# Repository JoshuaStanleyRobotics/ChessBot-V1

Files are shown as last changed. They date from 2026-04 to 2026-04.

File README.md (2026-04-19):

# ChessBot V1
ChessBot V1

This repository includes the PCB (gerber), CAD (.step), code (.ino and .py), and printing (.stl) files for ChessBot V1, an Arduino powered self-playing chess robot. 

A video overview of ChessBot V1 can be found here: [https://youtu.be/M-bemH251Hs](https://youtu.be/tLgXvUgsYmw)

The design has been updated slightly since the video, and the board coloring has been corrected to make A1 a black tile. The code is functional, but there is plenty of room for improvement. Feel free to modify the design and make it your own. Happy building! 

## Bill of Materials
| Component | Specs | Qty | Link |
|:---:|:-----:|:---:|:-----|
| ESP32 Dev Board | 38-pin version | 1 | https://www.amazon.com/dp/B0CNYK7WT2?ref_=ppx_hzsearch_conn_dt_b_fed_asin_title_14
| Electromagnet | 5V, 50N, 25mm diameter, 20mm height | 1 | |
| Motor Driver | DRV8872 | 1 |  |
| Hall Sensor | AH49FNTR-G1 | 64 |  |
| Momentary Switch | 6mm x 6mm | 2 |  |
| Barrel Jack Extension | 5.5x2.1mm | 1 | https://www.amazon.com/dp/B0D9B7WR23?ref_=ppx_hzsearch_conn_dt_b_fed_asin_title_1&th=1 |
| Power Supply | 7.5V, 36W, 5.5x2.1mm Barrel Jack | 1 | https://www.amazon.com/dp/B07N18XN84?ref_=ppx_hzsearch_conn_dt_b_fed_asin_title_3 |
| Stepper Driver | TMC2208 (or similar) | 2 |  |
| Stepper Motor | Nema 17, 22.5mm body height | 2 |  |
| Linear Rod | 8mm x 250mm | 2 |  |
| Linear Rod | 8mm x 265mm | 2 |  |
| Sleeve Bearing | 8mm ID, 10mm OD, 15mm length | 2 | https://www.amazon.com/dp/B07SLYD55F?ref_=ppx_hzsearch_conn_dt_b_fed_asin_title_4&th=1 |
| Sleeve Bearing | 8mm ID, 10mm OD, 6mm length | 6 | https://www.amazon.com/dp/B07SN3RBKW?ref_=ppx_hzsearch_conn_dt_b_fed_asin_title_1&th=1 |
| Timing Belt | 2GT 6mm | 5 meters |  |
| Belt Pulley | 2GT, 20 Teeth, 5mm ID | 2 |  |
| Idler Pulley | 3mm ID, 9.7mm OD, 13mm flange diameter, 8.5mm height | 12 |  |
| Neodymium Magnets | 8mm x 2mm | 32 |  |
| Button Head Screw | M3 x 30mm | 10 |  |
| Button Head Screw | M3 x 22mm | 2 |  |
| Button Head Screw | M3 x 12mm | 6 |  |
| Button Head Screw | M3 x 6mm | 8 |  |
| Washer | M3, 0.5mm thick | 50 |  |
| Threaded Insert | M3, 4mm thick | 24 |  |
| Rubber Feet | 3mm ID, 12mm OD, 6mm height | 4 |  |

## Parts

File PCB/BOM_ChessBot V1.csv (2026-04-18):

ID | Name | Designator | Footprint | Quantity | Manufacturer Part | Manufacturer | Supplier | Supplier Part | Price
1 | 10k | R1 | 1/4W RESISTOR | 1
2 | AH49F | A1,A2,A3,A4,A5,A6,A7,A8,B1,B2,B3,B4,B5,B6,B7,B8,C1,C2,C3,C4,C5,C6,C7,C8,D1,D2,D3,D4,D5,D6,D7,D8,E1,E2,E3,E4,E5,E6,E7,E8,F1,F2,F3,F4,F5,F6,F7,F8,G1,G2,G3,G4,G5,G6,G7,G8,H1,H2,H3,H4,H5,H6,H7,H8 | SC-59-3_L2.9-W1.6-P0.95-LS2.9-BR | 64 | AH49FNTR-G1 | DIODES(美台) | LCSC | C176936 | 0.535
3 | Stepper_Driver | U3,U4 | STEPPER_DRIVER | 2
4 | 100uF | C9,C10 | 8X12 CAP | 2
5 | ESP-WROOM-32 | U1 | ESP32 | 1
6 | XHB-2A | 5V,VCC | CONN-TH_XHB-2A | 2 | XHB-2A | BOOMELE(博穆精密) | LCSC | C57981 | 0.013
7 | HDR-M-2.54_1x6 | CN1 | HDR-M-2.54_1X6 | 1 |  |  | LCSC | C190819 | 0.041
8 | DRV8872DDARQ1 | U5 | SO-8_L4.9-W3.9-P1.27-LS6.0-BL-EP5.1 | 1 | DRV8872DDARQ1 | TI(德州仪器) | LCSC | C524788 | 1.79
9 | HDR-M-2.54_1x4 | M1,M2 | HDR-M-2.54_1X4 | 2 |  |  | LCSC | C124378 | 0.055

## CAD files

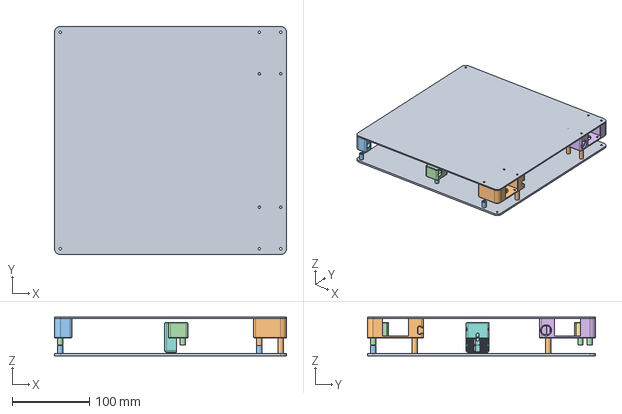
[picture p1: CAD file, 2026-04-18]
CAD/ChessBot V1.step
300.0 x 295.0 x 50.0 mm

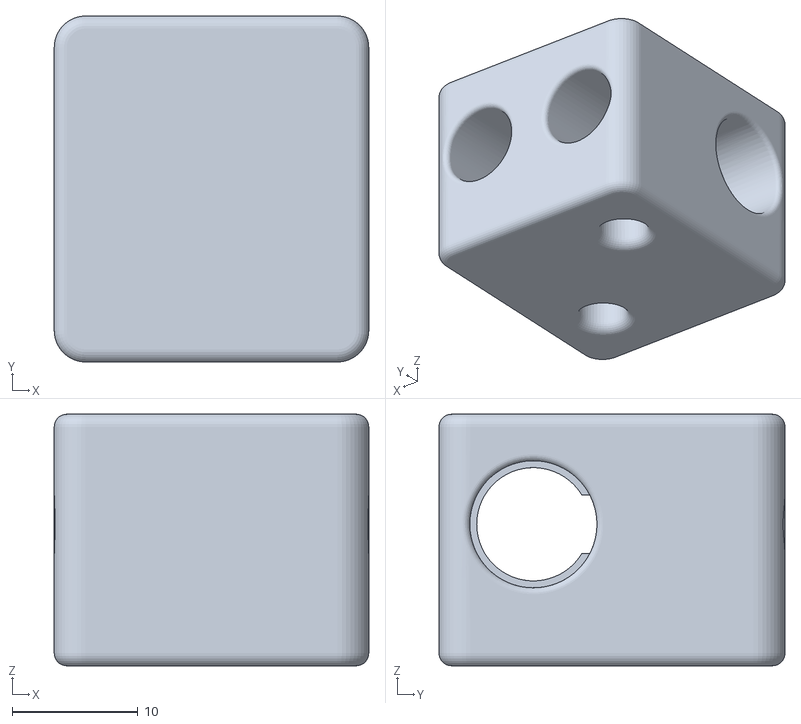
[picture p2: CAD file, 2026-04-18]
STLs/Gantry Carriage (A) - Qty 1.stl
25.0 x 27.5 x 20.0

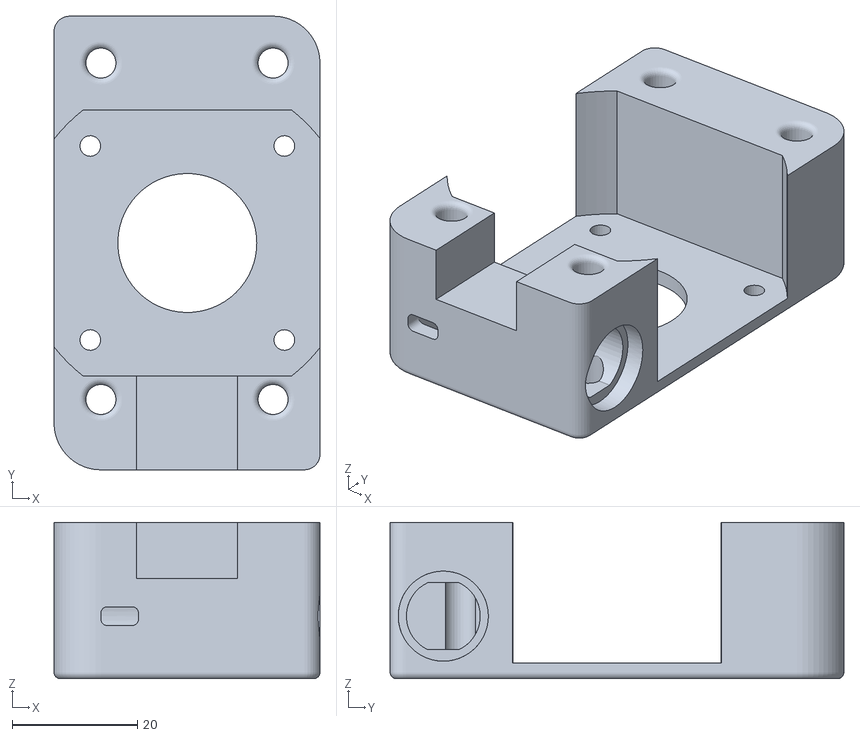
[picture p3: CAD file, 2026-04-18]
STLs/Motor Housing (B) - Qty 1.stl
42.5 x 72.5 x 25.0

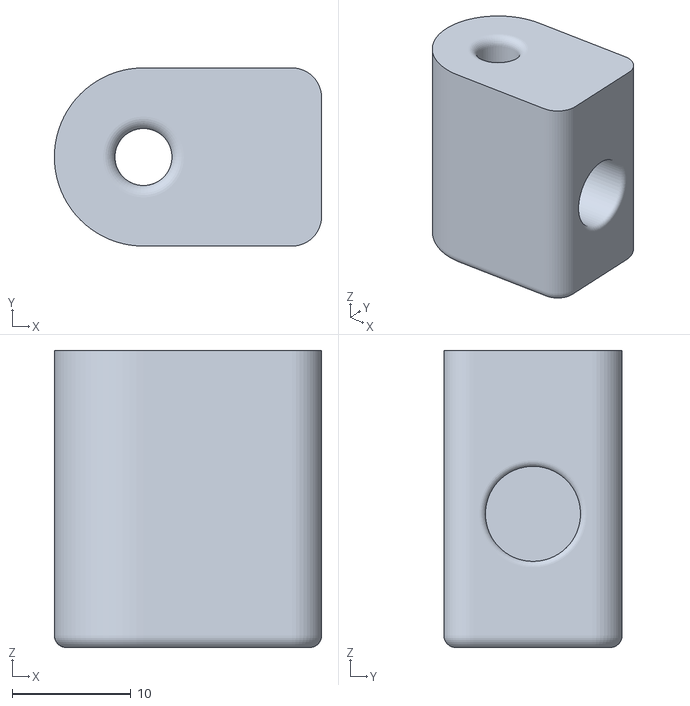
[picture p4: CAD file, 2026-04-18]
STLs/Corner Support - Qty 2.stl
22.5 x 15.0 x 25.0

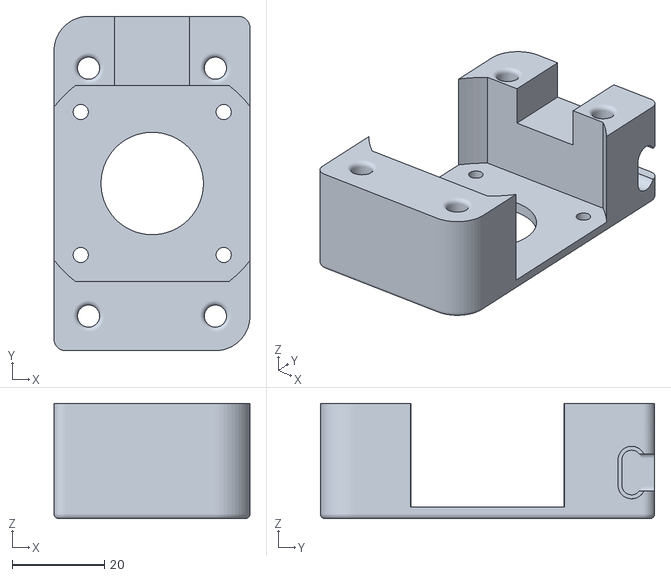
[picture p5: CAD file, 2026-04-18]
STLs/Motor Housing (A) - Qty 1.stl
42.5 x 72.5 x 25.0

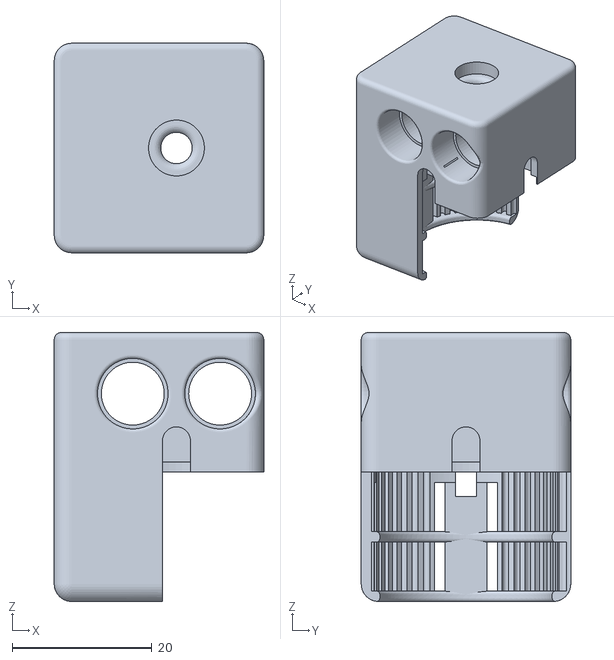
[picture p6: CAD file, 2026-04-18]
STLs/Magnet Carriage- Qty 1.stl
30.0 x 30.0 x 38.5

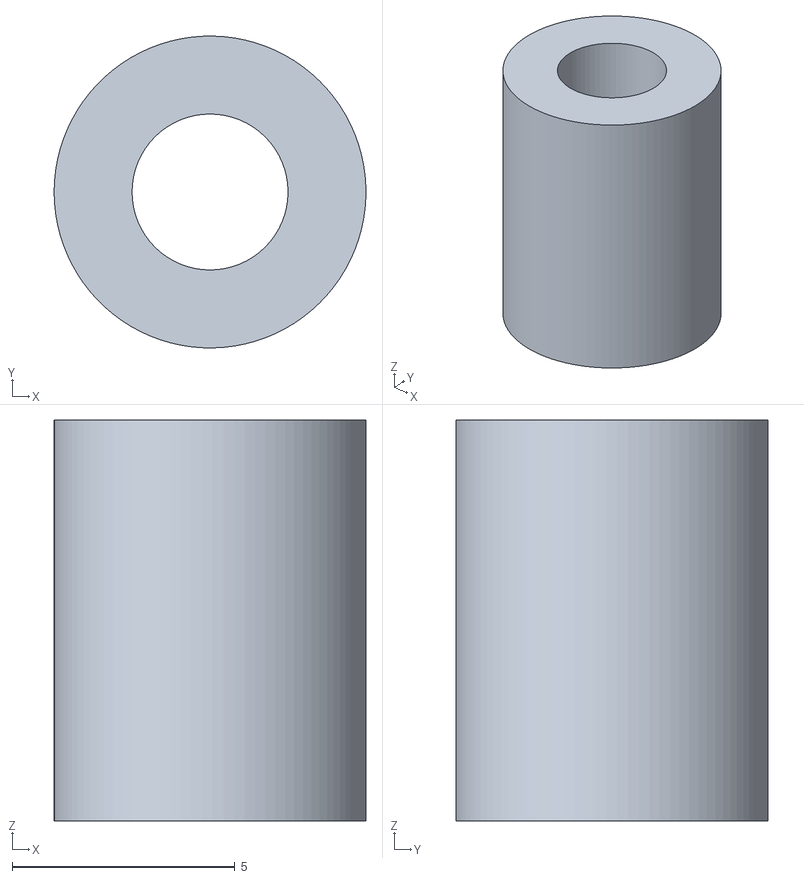
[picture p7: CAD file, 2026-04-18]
STLs/Spacer (short) - Qty 6.stl
7.00 x 7.00 x 9.00

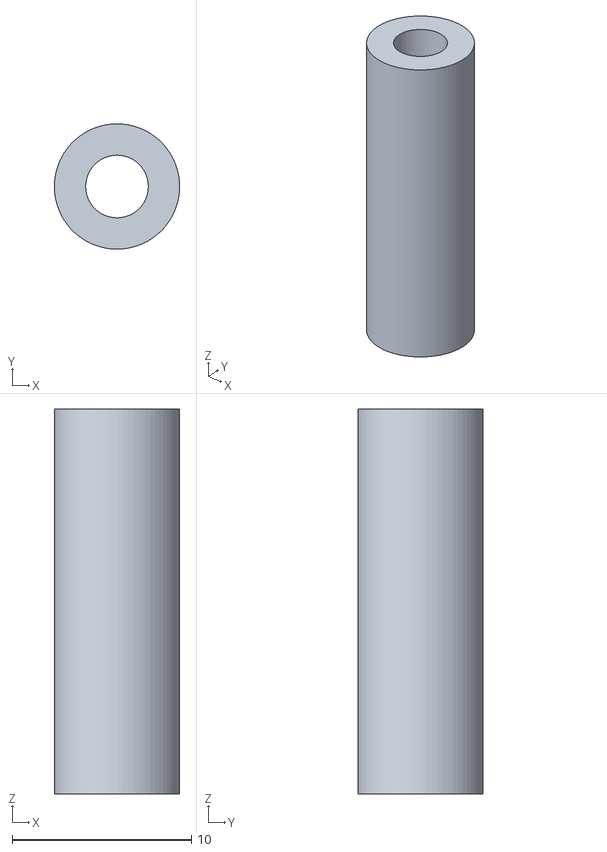
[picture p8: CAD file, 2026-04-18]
STLs/Spacer (long) - Qty 4.stl
7.00 x 7.00 x 21.5

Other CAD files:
STLs/Gantry Carriage (B) - Qty 1.stl

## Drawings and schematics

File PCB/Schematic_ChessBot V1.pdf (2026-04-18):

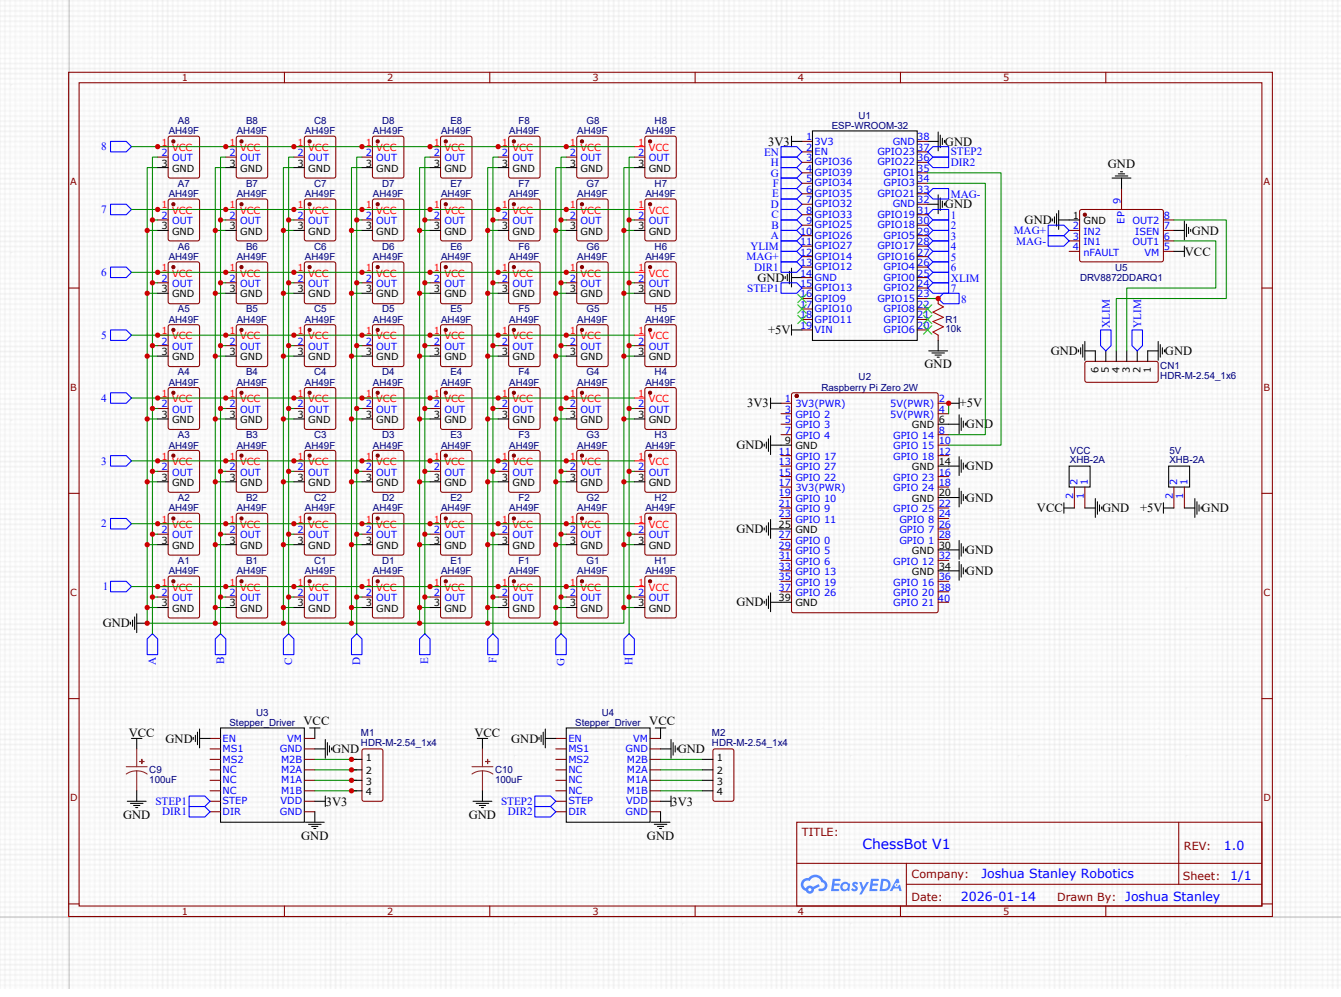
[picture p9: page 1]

Company: Joshua Stanley Robotics

Drawn By: Joshua Stanley

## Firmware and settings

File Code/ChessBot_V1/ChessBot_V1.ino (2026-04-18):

/*
   Description: This program is used to control a chess robot that reads the board state using hall effect sensors and moves pieces with an electromagnet on a coreXY motion system.
        The player's moves are communicated over serial to a computer running Stockfish which takes in the user's moves and responds with the computer's moves.
*/

//Libraries
#include "AccelStepper.h"
const int step1 = 23, dir1 = 22, step2 = 13, dir2 = 12;           //Pinout for stepper drivers
const int spd = 1500;                                             //Max stepper motor speed
AccelStepper M1(AccelStepper::DRIVER, step1, dir1);
AccelStepper M2(AccelStepper::DRIVER, step2, dir2);

#include "MultiStepper.h"
MultiStepper motors;

//Pin Declarations
const int row[] = {19, 18, 5, 17, 16, 4, 2, 15};                  //Pinout for magnetic sensor supply by row
const int col[] = {26, 25, 33, 32, 35, 34, 39, 36};               //Pinout for magnetic sensor output by column
const int xLim = 0;                                               //Pinout for X-axis limit switch
const int yLim = 27;                                              //Pinout for Y-axis limit switch
const int mag[] = {14, 21};                                       //Pinouts driving electromagnet

//Constants
const int neutral[8][8] = {                                       //Array of magnetic sensor readings with no magnet present. Upadate with your own values determined experimentally
  {1535, 1535, 1557, 1520, 1555, 1526, 1569, 1507},
  {1490, 1586, 1600, 1535, 1535, 1531, 1535, 1520},
  {1581, 1560, 1557, 1535, 1533, 1511, 1553, 1535},
  {1535, 1504, 1494, 1502, 1535, 1441, 1489, 1498},
  {1525, 1507, 1509, 1503, 1531, 1531, 1535, 1523},
  {1560, 1557, 1573, 1557, 1531, 1575, 1519, 1520},
  {1568, 1584, 1513, 1527, 1511, 1522, 1575, 1513},
  {1579, 1507, 1535, 1535, 1524, 1535, 1535, 1527}
};

//Variables
long positions[2] = {0, 0};                                       //Array for motor positions
char board[8][9] = {"RP    pr", "NP    pn", "BP    pb", "QP    pq", "KP    pk", "BP    pb", "NP    pn", "RP    pr"};
bool currentBoard[8][8];
bool previousBoard[8][8];

char ply[6];
bool turn = 1;
bool invalid = 0;
bool debugging = 0;


void setup() {
  Serial.begin(115200);                                           //Initialize serial communication
  while (!Serial);

  for (int i = 0; i < 8; i++) {                                   //Initialize I/O pins
    pinMode(row[i], OUTPUT);
    pinMode(col[i], INPUT);
  }
  pinMode(step1, OUTPUT);
  pinMode(dir1, OUTPUT);
  pinMode(step2, OUTPUT);
  pinMode(dir2, OUTPUT);
  pinMode(xLim, INPUT_PULLUP);
  pinMode(yLim, INPUT_PULLUP);
  pinMode(mag[0], OUTPUT);
  pinMode(mag[1], OUTPUT);
  analogWrite(mag[0], LOW);
  analogWrite(mag[1], LOW);

  M1.setMaxSpeed(spd);                                            //Configure stepper motors
  M2.setMaxSpeed(spd);
  zero();                                                         //Function to home coreXY motion system
  motors.addStepper(M1);
  motors.addStepper(M2);

  scanBoard();
  for (int j = 0; j < 8; j++) {
    for (int i = 0; i < 8; i++) {
      previousBoard[i][j] = currentBoard[i][j];
    }
  }
  if (debugging) {
    for (int j = 7; j > -1; j--) {
      Serial.println("+---+---+---+---+---+---+---+---+");
      Serial.print("| ");
      for (int i = 0; i < 8; i++) {
        Serial.print(currentBoard[i][j]);
        Serial.print(" | ");
      }
      Serial.println("");
    }
    Serial.println("+---+---+---+---+---+---+---+---+");
  }
  delay(250);
}


void loop() {
  if (turn) {                                                     //Player's turn
    scanBoard();
    if (compareBoard()) {                                         //Compare to the previous board state to see if a move was made
      if (board[ply[0] - 97][ply[1] - 49] == 'P' && ply[3] == '8') { //if pawn makes it to opposite side, promote to queen
        if (debugging) Serial.println("Promoting to Queen");
        board[ply[0] - 97][ply[1] - 49] = 'Q';
        ply[4] = 'q';
      }
      if ((board[ply[0] - 97][ply[1] - 49] == 'K') && (ply[0] == 'e' && ply[1] == '1')) { //Look for castling move
        if (ply[2] == 'c') {      //Queen side castling
          board[0][0] = ' ';
          board[3][0] = 'R';
          delay(2000);
        }
        else if (ply[2] == 'g') { //King side castling
          board[7][0] = ' ';
          board[5][0] = 'R';
          delay(2000);
        }
      }
      updateBoard(ply);                                           //Update the board array with the player ply
      Serial.println(ply);                                        //Send the player's move to the computer
      for (int i = 0; i < 5; i++) ply[i] = ' ';
      turn = 0;                                                   //Switch to the computer player's turn
    }
  }

  else {                                                          //Computer's turn
    while (Serial.available() == 0) delay(5);                     //Wait for a serial input
    String response = Serial.readStringUntil('\n');
    if (debugging) Serial.println(response);
    response.toCharArray(ply, 6);

    if (board[ply[0] - 97][ply[1] - 49] == ' ') {                 //if the departing tile is empty, an invalid move was sent back
      if (debugging) Serial.print("Invalid move sent: ");
      invalid = 1;
      char reverse[5];
      for (int i = 0; i < 5; i++) reverse[i] = ply[i];
      if (debugging) Serial.println(reverse);

      ply[0] = reverse[2];
      ply[1] = reverse[3];
      ply[2] = reverse[0];
      ply[3] = reverse[1];
    }
    else if (board[ply[2] - 97][ply[3] - 49] != ' ') {            //if the destination tile is occupied, topple the captured piece and remove it from the board state
      if (debugging) Serial.println("Toppling Piece");
      goTo(ply[2] - 97, ply[3] - 49);
      analogWrite(mag[1], 255);
      delay(5);
      analogWrite(mag[1], 0);
      currentBoard[ply[2] - 97][ply[3] - 49] = 0;
    }

    if (board[ply[0] - 97][ply[1] - 49] != 'n' && board[ply[0] - 97][ply[1] - 49] != 'N') {                   //typical move
      goTo(ply[0] - 97, ply[1] - 49);
      analogWrite(mag[!invalid], 255);
      goTo(ply[2] - 97, ply[3] - 49);
      pulse(!invalid);
      updateBoard(ply);
    }
    else {                                                        //knight move special case
      if (debugging) Serial.println("Knight Move!");
      goTo(ply[0] - 97, ply[1] - 49);
      analogWrite(mag[!invalid], 255);
      goTo(ply[0] - 97 + 0.5 * ((ply[2] - ply[0]) / (abs(ply[2] - ply[0]))), ply[1] - 49 + 0.5 * ((ply[3] - ply[1]) / (abs(ply[3] - ply[1]))));
      analogWrite(mag[!invalid], 155); //60% power 155
      goTo(ply[2] - 97 - 0.5 * ((ply[2] - ply[0]) / (abs(ply[2] - ply[0]))), ply[3] - 49 - 0.5 * ((ply[3] - ply[1]) / (abs(ply[3] - ply[1]))));
      analogWrite(mag[!invalid], 255);
      delay(5);
      goTo(ply[2] - 97, ply[3] - 49);
      pulse(!invalid);
      updateBoard(ply);
    }

    if ((board[ply[2] - 97][ply[3] - 49] == 'k') && (ply[0] == 'e' && ply[2] == 'g')) { //king side castling special case
      if (debugging) Serial.println("King Side Castling");
      goTo('h' - 97, '8' - 49);
      analogWrite(mag[!invalid], 255);
      goTo('h' - 97.5, '8' - 49.5);
      analogWrite(mag[!invalid], 170);
      goTo('g' - 97.5, '8' - 49.5);
      analogWrite(mag[!invalid], 255);
      delay(5);
      goTo('f' - 97, '8' - 49);
      pulse(!invalid);
      updateBoard("h8f8");
    }
    else if ((board[ply[2] - 97][ply[3] - 49] == 'k') && (ply[0] == 'e' && ply[2] == 'c')) { //queen side castling special case
      if (debugging)Serial.println("Queen Side Castling");
      goTo('a' - 97, '8' - 49);
      analogWrite(mag[!invalid], 255);
      goTo('b' - 97.5, '8' - 49.5);
      analogWrite(mag[!invalid], 170);
      goTo('d' - 97.5, '8' - 49.5);
      analogWrite(mag[!invalid], 255);
      delay(5);
      goTo('d' - 97, '8' - 49);
      pulse(!invalid);
      updateBoard("a8d8");
    }

    if (ply[4] == '+') {                                          //Check: bump king
      for (int i = 0; i < 8; i++) {
        for (int j = 0; j < 8; j++) {
          if (board[i][j] == 'K') {
            goTo(i, j);
            analogWrite(mag[1], 255);
            delay(5);
            analogWrite(mag[1], 0);
          }
        }
      }
    }
    else if (ply[4] == '#') {                                     //Checkmate: topple king
      for (int i = 0; i < 8; i++) {
        for (int j = 0; j < 8; j++) {
          if (board[i][j] == 'K') {
            goTo(i, j);
            analogWrite(mag[1], 255);
            delay(20);
            analogWrite(mag[1], 0);
          }
        }
      }
    }

    invalid = 0;
    turn = 1;                                                     //Switch to the player's turn
    for (int i = 0; i < 5; i++) ply[i] = ' ';
  }
  delay(100);
}


void scanBoard() {                                                //Scans the sensor array for all the black pieces
  for (int j = 0; j < 8; j++) {
    digitalWrite(row[j], 255);
    for (int i = 0; i < 8; i++) {
      //int val = analogRead(col[i]) - neutral[j][i];
      //Serial.print(String(val) + '\t');
      if (neutral[j][i] - analogRead(col[i]) > 200) currentBoard[i][j] = 1;
      else currentBoard[i][j] = 0;
    }
    //Serial.println("");
    digitalWrite(row[j], LOW);
  }
  //Serial.println('\n');
}

bool compareBoard() {                                             //Compares the current board with the previous board and determines if a move was made
  bool departed = 0;
  bool arrived = 0;
  for (int j = 0; j < 8; j++) {
    for (int i = 0; i < 8; i++) {
      if (currentBoard[i][j] != previousBoard[i][j]) {
        if (currentBoard[i][j]) {
          arrived = 1;
          ply[2] = i + 97;
          ply[3] = j + 49;
        }
        else {
          departed = 1;
          ply[0] = i + 97;
          ply[1] = j + 49;
        }
      }
    }
  }
  if (departed && arrived) return 1;                              //If a piece left one tile and arrived on another, then a full ply was detected
  else return 0;
}

void updateBoard(char p[]) {
  board[p[2] - 97][p[3] - 49] = board[p[0] - 97][p[1] - 49];      //update piece on destination tile
  board[p[0] - 97][p[1] - 49] = ' ';                              //remove piece from departed tile

  scanBoard();
  for (int j = 0; j < 8; j++) {
    for (int i = 0; i < 8; i++) {
      previousBoard[i][j] = currentBoard[i][j];
    }
  }
  if (debugging) {
    for (int j = 7; j > -1; j--) {
      Serial.println("+---+---+---+---+---+---+---+---+");
      Serial.print("| ");
      for (int i = 0; i < 8; i++) {
        //Serial.print(currentBoard[i][j]);
        Serial.print(board[i][j]);
        Serial.print(" | ");
      }
      Serial.println("");
    }
    Serial.println("+---+---+---+---+---+---+---+---+");
  }
}

void goTo(float xPos, float yPos) {
  if (debugging) Serial.println("  Position: " + String(xPos) + ", " + String(yPos));
  yPos = yPos - 7;                                                //Translate the coordinate system
  positions[0] = 1200 * (xPos - yPos);                            //Rotate the coordinate system (for coreXY motion)
  positions[1] = 1200 * (xPos + yPos);

  //if (debugging) Serial.println("  Motor Position: " + String(positions[0]) + ", " + String(positions[1]));
  //if (debugging) Serial.println("");
  motors.moveTo(positions);
  motors.runSpeedToPosition();
}

void pulse(bool polarity) {                                       //Pulse the magnet to center a piece
  analogWrite(mag[polarity], 0);
  analogWrite(mag[!polarity], 255);
  delay(10);
  analogWrite(mag[!polarity], 0);
  analogWrite(mag[polarity], 255);
  delay(100);
  analogWrite(mag[polarity], 0);
}

void zero() {
  if (debugging) Serial.print("Homing X-Axis");
  M1.setSpeed(-1000);
  M2.setSpeed(-1000);
  while (digitalRead(xLim)) {
    M1.runSpeed();
    M2.runSpeed();
    if (debugging) Serial.print(".");
    delay(1);
  }
  M1.setSpeed(0);
  M2.setSpeed(0);
  M1.runSpeed();
  M2.runSpeed();
  if (debugging) Serial.println("");

  if (debugging) Serial.print("Homing Y-Axis");
  M1.setSpeed(-1000);
  M2.setSpeed(1000);
  while (digitalRead(yLim)) {
    M1.runSpeed();
    M2.runSpeed();
    if (debugging) Serial.print(".");
    delay(1);
  }
  M1.setSpeed(0);
  M2.setSpeed(0);
  M1.runSpeed();
  M2.runSpeed();
  if (debugging) Serial.println("");
  M1.setCurrentPosition(0);
  M2.setCurrentPosition(0);
}

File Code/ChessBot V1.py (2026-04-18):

import serial
ser = serial.Serial('COM22', 115200, timeout=None)

import chess
import chess.engine
engine = chess.engine.SimpleEngine.popen_uci("C:\Program Files (x86)\Stockfish\stockfish-windows-x86-64-avx2.exe")
engine.configure({"Threads":4, "Hash":16, "Skill Level":20})

board = chess.Board()
limit = chess.engine.Limit(time=.1)

try:
    while board.is_checkmate() != True:                                                 # gameplay loop to repeat until the game is over
        move = ser.readline().decode('utf-8').rstrip()                                  # read in move from the microcontroller
        if move:                                                                        # if a move was received 
            print(f"Received: {move}")                                                  # print the recieved move in the command line
            
            try:
                move = chess.Move.from_uci(move)                                        # convert the UCI string to a move object
            except chess.InvalidMoveError:
                print(f"'{move}' is an invalid UCI format string.")                     # if the move is invalid 
                response = f"{move}\n"
                ser.write(response.encode('utf-8'))
                print(f"Sent: {move}")
                move = None

            if move is not None and move in board.legal_moves:                          # check if the move is in the list of legal moves                                
                board.push(move)                                                        # if legal, make the move on the board
                print(board)
                print('\n')

                result = engine.play(board, limit)                                      # get the best response
                best_move = result.move

                board.push(best_move)                                                   # update the response on the board

                if board.is_checkmate():
                    response = f"{best_move}#\n"
                    print(f"Checkmate")
                elif board.is_check():
                    response = f"{best_move}+\n"
                    print(f"Check")
                else:
                    response = f"{best_move}\n"
                
                ser.write(response.encode('utf-8'))                                     # write the response to the microcontroller
                print(f"Sent: {response}")
                print(board)

            else:
                print(f"The move '{move}' is not legal in the current position.")
                response = f"{move}\n"
                ser.write(response.encode('utf-8'))
                print(f"Sent: {move}")
                move = None
    print(f"Check Mate")
    


except KeyboardInterrupt:
    print("Program terminated by user.")
finally:
    ser.close()
    engine.quit()
